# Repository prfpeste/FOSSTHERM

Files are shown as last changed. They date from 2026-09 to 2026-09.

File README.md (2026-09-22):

# FOSSTHERM

Freie und quelloffene Soft- und Hardware für thermische Tischversuche

> **English summary:** FOSSTHERM (Free and Open Source Thermal Experiments) is a collection of Arduino-based benchtop experiments for teaching heat transfer and thermodynamics. Each experiment lives in its own folder and includes hardware files (3D-printable parts, schematics, bill of materials), firmware, evaluation software and documentation. The documentation is written in German; source code and file names are in English.

## Projektziel

Das System wurde bewusst nicht als vollständig industrialisiertes Messsystem ausgelegt, sondern als leicht nachbaubare, offene und kostengünstige Plattform für den Einsatz in Lehre und Labor. Im Vordergrund stehen geringe Materialkosten, die Verwendung gut verfügbarer Standardbauteile, eine leicht nachvollziehbare Schaltungstopologie sowie die Möglichkeit, dass Studierende Module selbst aufbauen, anpassen und im Fehlerfall mit geringem Aufwand austauschen können.

Zusätzliche Maßnahmen zur Erhöhung der Robustheit, der EMV-Festigkeit oder für einen umfassenden Fehlerschutz wurden daher nur insoweit berücksichtigt, wie sie für den vorgesehenen Einsatz in beaufsichtigten Laborumgebungen erforderlich sind. Für Anwendungen in rauen Industrieumgebungen oder mit erhöhten Anforderungen an Zuverlässigkeit und Störfestigkeit sind weitergehende Schutz- und Schnittstellenbeschaltungen notwendig.

Die Versuche entstehen im Rahmen studentischer Projektarbeiten und richten sich an Hochschulen, Schulen und alle, die thermische Grundlagen anschaulich und messtechnisch nachvollziehbar vermitteln möchten.

## Versuche

| Versuch | Inhalt | Status |
| :--- | :--- | :--- |
| [Wärmekapazität](Waermekapazitaet/) | Bestimmung der spezifischen Wärmekapazität von Aluminium, Kupfer und Stahl mittels Wasserkalorimetrie | verfügbar |
| Wärmeleitfähigkeit | | in Arbeit |
| Tripelpunkt | | in Arbeit |

Weitere Versuche werden ergänzt, sobald sie fertiggestellt sind.

## Aufbau des Repositorys

Jeder Versuch liegt in einem eigenen Unterordner mit einheitlicher Gliederung:

```
FOSSTHERM/
├── README.md                  Diese Datei
├── LICENSE-*                  Lizenztexte für Hardware, Software und Dokumentation
└── <Versuch>/
    ├── README.md              Überblick und Schnellstart zum Versuch
    ├── 01_Hardware/           Stückliste, 3D-Druckteile, Zeichnungen, Schaltplan
    ├── 02_Software/           Firmware, Auswertesoftware, Simulation
    └── 03_Documentation/      Handbuch mit Theorie, Bedienung und Sicherheitshinweisen
```

Die README im jeweiligen Versuchsordner beschreibt, welche Dateien im Einzelnen enthalten sind und wie der Versuch in Betrieb genommen wird.

## Mitwirkende

#### Projektleitung und Betreuung

- Prof. Dr. Peter Stein (HTWG Konstanz - Maschinenbau)

#### Entwicklung der Versuche

- Marcel Yigitkurt (Waermekapazitaet - HTWG Konstanz - Maschinenbau)
- Moritz Schubach (Waermekapazitaet - HTWG Konstanz - Maschinenbau)

## Verwandte Projekte

- [FOSSDAQ](https://github.com/prfpeste/FOSSDAQ) – freie und quelloffene modulare Messdatenerfassung für Lehre und Labor

## Lizenz

FOSSTHERM verwendet für verschiedene Teile des Projekts unterschiedliche Lizenzen:

- **Hardware und Konstruktionsdaten** in den Ordnern `01_Hardware/` der einzelnen Versuche unterliegen der Lizenz **CERN-OHL-W-2.0**.
  Siehe [`LICENSE-HARDWARE - CERN-OHL-W-2.0`](LICENSE-HARDWARE%20-%20CERN-OHL-W-2.0).

- **Firmware und Software** in den Ordnern `02_Software/` unterliegen der Lizenz **GPL-3.0-or-later**.
  Siehe [`LICENSE-SOFTWARE - GPL-3.0`](LICENSE-SOFTWARE%20-%20GPL-3.0).

- **Dokumentation** in den Ordnern `03_Documentation/` sowie die README-Dateien unterliegen der Lizenz **CC-BY-SA-4.0**.
  Siehe [`LICENSE-DOCS - CC-BY-SA-4.0`](LICENSE-DOCS%20-%20CC-BY-SA-4.0).

Sofern nicht ausdrücklich anders angegeben, gelten für neue Dateien die Lizenzen ihres übergeordneten Verzeichnisses.

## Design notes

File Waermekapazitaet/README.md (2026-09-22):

# Versuch: Wärmekapazität

Teil von [FOSSTHERM](../README.md) – freie und quelloffene thermische Tischversuche

> **English summary:** Arduino-based benchtop experiment for determining the specific heat capacity of metal samples (aluminium, copper, steel) by water calorimetry. This folder contains 3D-printable parts, a KiCad schematic, Arduino firmware, a Python/Dash dashboard and an OpenModelica model. The documentation is written in German; source code and file names are in English.

## Überblick

In diesem Versuch wird die **spezifische Wärmekapazität metallischer Proben** (Aluminium, Kupfer und Stahl) mittels **Wasserkalorimetrie** bestimmt. Die Probe wird mit Raumtemperatur in heißes Wasser getaucht; aus der Abkühlung des Wassers und der Erwärmung der Probe berechnet das Dashboard automatisch die Wärmekapazität.

Der Aufbau besteht aus:

- einem **Arduino Nano**,
- einem **DS18B20-Temperatursensor** für die Wassertemperatur,
- einem **MAX6675-Messverstärker mit Typ-K-Thermoelement** für die Probentemperatur,
- einem **Python-Dash-Dashboard** zur Live-Messwerterfassung und Berechnung der Wärmekapazität mit Wärmeverlustkorrektur,
- einem **digitalen Zwilling in OpenModelica** zur Simulation und Validierung sowie
- einer **vollständig 3D-druckbaren Mechanik**.

## Aufbau des Ordners

- `README.md`
  Diese Datei: Überblick, Ordneraufbau und Schnellstart.

- `01_Hardware/`
  - `BOM.ods`: Stückliste mit Bezugsquellen und 3D-Druckteilen.
  - `CAD_construction/STL/`: STL-Dateien aller 3D-druckbaren Teile (Grundplatte, Becherhalter, Deckel, Gehäuse, Kabelschellen, Tauchsiederhalterung, Probenhalter usw.).
  - `CAD_construction/test_cube.pdf`: Zeichnung des Probenwürfels.
  - `electrical_schematic/`: KiCad-Schaltplan (`PJ1_Tischversuch_Schaltplan.kicad_sch`) und als PDF exportierter Schaltplan.

- `02_Software/`
  - `Arduino/`: Firmware (`heat_capacity_sketch.ino`) und Liste der benötigten Bibliotheken (`libraries.txt`).
  - `Python/`: Dash-Anwendung (`HeatCapacity_python_code.py`) zur Live-Visualisierung, CSV-Export und Berechnung der Wärmekapazität, Hilfsskript zur Kalibrierung des Wärmeverlusts (`determine_heat_loss_coefficient.py`), Startskript für Linux/macOS (`run_HeatCapacity.sh`) sowie Beispielmessdaten in `data/`.
  - `Open_Modelica_simulation/`: Digitaler Zwilling des Kalorimetrieversuchs (`HeatCapacity_Experiment.mo`) zur Simulation und Validierung.

- `03_Documentation/`
  - `MANUAL.md`: Technisches Handbuch mit Theorie, Kalibrierung, Pinbelegung, Bedienungsanleitung, Sicherheitshinweisen und Fehlersuche.

## Schnellstart

### 1. Firmware

1. `02_Software/Arduino/heat_capacity_sketch.ino` in der Arduino-IDE öffnen.
2. Board **Arduino Nano** auswählen.
3. Über den Bibliotheksverwalter die benötigten Bibliotheken installieren: LiquidCrystal I2C, OneWire, DallasTemperature und MAX6675 (siehe `libraries.txt`).
4. Den richtigen Port wählen und den Sketch hochladen.

### 2. Python-Dashboard

```bash
git clone https://github.com/prfpeste/FOSSTHERM.git
cd FOSSTHERM/Waermekapazitaet/02_Software/Python
python -m venv .venv
source .venv/bin/activate      # Windows: .venv\Scripts\activate
pip install -r requirements.txt
```

Vor dem ersten Start in `HeatCapacity_python_code.py` die Konstante `SERIAL_PORT` an den seriellen Port des Arduino anpassen (voreingestellt ist `COM5`; unter Linux z. B. `/dev/ttyUSB0`, unter macOS z. B. `/dev/cu.usbserial-…`). Anschließend:

```bash
python HeatCapacity_python_code.py
```

Unter Linux/macOS kann alternativ `./run_HeatCapacity.sh` verwendet werden; das Skript legt die virtuelle Umgebung bei Bedarf selbst an.

Danach im Browser http://127.0.0.1:8050 öffnen, Wassermasse, Raumtemperatur und Probenmaterial eingeben und den Versuch starten. Den genauen Messablauf beschreibt das [Handbuch](03_Documentation/MANUAL.md).

### 3. Digitaler Zwilling (optional)

`02_Software/Open_Modelica_simulation/HeatCapacity_Experiment.mo` in OpenModelica (OMEdit) öffnen, um den Kalorimetrievorgang zu simulieren und mit einem aus dem Dashboard exportierten CSV-Datensatz zu vergleichen. Hinweise dazu stehen in der [README des Simulationsordners](02_Software/Open_Modelica_simulation/README.md).

## Voraussetzungen

- Python 3.10 oder neuer (siehe `02_Software/Python/requirements.txt`)
- Arduino-IDE 2.x mit Boardpaket für den Arduino Nano
- OpenModelica 1.22 oder neuer (nur für den digitalen Zwilling)

## Entwicklung des Versuchs

- Marcel Yigitkurt
- Moritz Schubach

## Lizenz

Für die Bestandteile dieses Versuchs gelten die Lizenzen des FOSSTHERM-Repositorys; die Lizenztexte liegen im Hauptverzeichnis:

- **Hardware** (`01_Hardware/`: Schaltplan, 3D-Modelle, Zeichnungen, Stückliste) steht unter **CERN-OHL-W-2.0**.
  Siehe [`LICENSE-HARDWARE - CERN-OHL-W-2.0`](../LICENSE-HARDWARE%20-%20CERN-OHL-W-2.0).

- **Firmware und Software** (`02_Software/`: Arduino, Python, OpenModelica) stehen unter **GPL-3.0-or-later**.
  Siehe [`LICENSE-SOFTWARE - GPL-3.0`](../LICENSE-SOFTWARE%20-%20GPL-3.0).

- **Dokumentation** (`03_Documentation/` und die README-Dateien) steht unter **CC-BY-SA-4.0**.
  Siehe [`LICENSE-DOCS - CC-BY-SA-4.0`](../LICENSE-DOCS%20-%20CC-BY-SA-4.0).

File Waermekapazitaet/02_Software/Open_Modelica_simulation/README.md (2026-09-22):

# OpenModelica: Digitaler Zwilling

Dieser Ordner enthält das physikalische Simulationsmodell des Wärmekapazitäts-Versuchs, erstellt mit OpenModelica. Es dient dazu, den theoretischen Temperaturverlauf zu simulieren und mit den realen, über Python erfassten Sensordaten zu vergleichen.

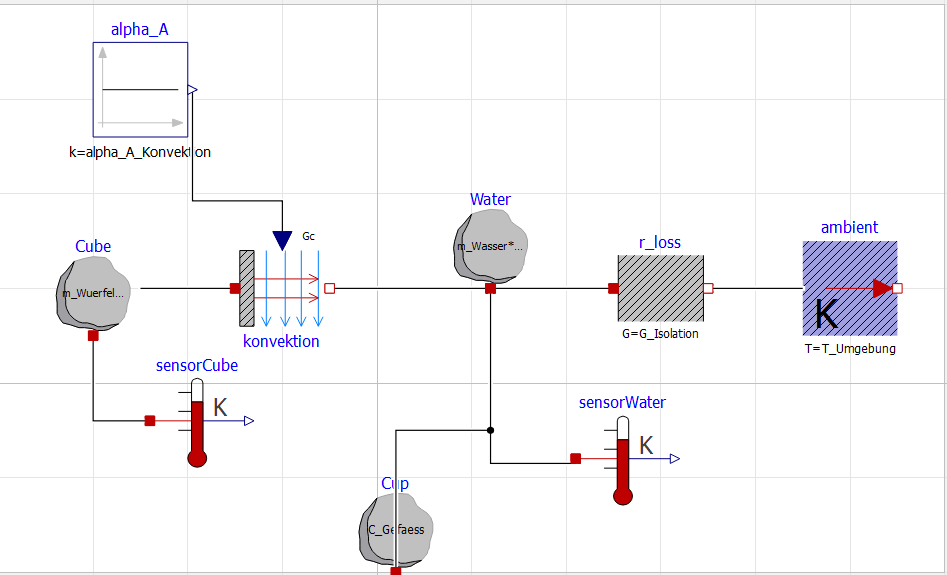
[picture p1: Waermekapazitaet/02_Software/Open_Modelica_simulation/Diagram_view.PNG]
Diagrammansicht des Modells


## Verwendung in OMEdit

1. Die Datei `HeatCapacity_Experiment.mo` in OMEdit öffnen (Modellname: `HeatCapacity_TableTopExperiment_MaterialSelection`).
2. In die **Diagrammansicht** (Diagram View) wechseln.
3. Doppelt auf den leeren Hintergrund klicken, um das Parametermenü zu öffnen. Dort das Material auswählen (`materialSelection`):
   * `1` = Aluminium
   * `2` = Kupfer
   * `3` = Stahl
4. Auf **Simulate** klicken.

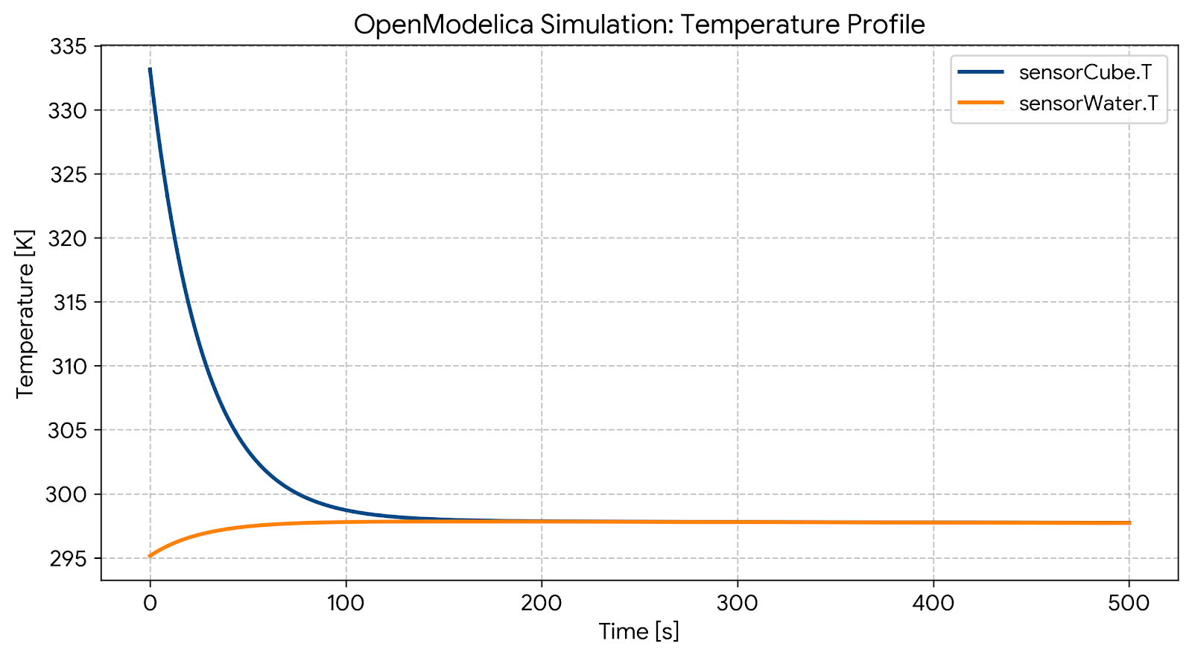
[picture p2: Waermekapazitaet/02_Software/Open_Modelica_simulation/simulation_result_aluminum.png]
Simulationsergebnis für Aluminium


## Starttemperaturen

In der Voreinstellung simuliert das Modell einen heißen Würfel (`T_Wuerfel_Start` = 60 °C) in kaltem Wasser (`T_Wasser_Start` = 22 °C). Im realen Versuch ist es umgekehrt: Der Würfel hat Raumtemperatur und wird in Wasser von ca. 60 °C getaucht. Für einen direkten Vergleich mit Messdaten die beiden Parameter entsprechend tauschen und `T_Umgebung` auf die gemessene Raumtemperatur setzen. Die Auswertungsgleichungen im Modell gelten für beide Richtungen des Wärmeflusses.

## Kalibrierung

Der Parameter `alpha_A_Konvektion` (Wärmeübergang Würfel–Wasser, α·A in W/K) ist im Modell auf `3.5` kalibriert. Mit diesem Wert stellt sich das thermische Gleichgewicht zwischen Aluminiumwürfel und Wasser in der Simulation nach etwa 110 Sekunden ein, wie im realen Laboraufbau.

Der Parameter `G_Isolation` entspricht dem Wärmeverlustkoeffizienten `K_WERT` der Python-Auswertung. Nach einer neuen Kalibrierung (siehe `03_Documentation/MANUAL.md`, Abschnitt 2) sollte er auf denselben Wert gesetzt werden.

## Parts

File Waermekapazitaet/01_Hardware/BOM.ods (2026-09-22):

Bauteil | Genaue Bezeichnung | EAN | Preis pro Stück(ca.) | Stückzahl | Link
Arduino Nano Clon | TRU COMPONENTS MF-6402378 Entwicklungsboard ATmega328 NANO Development Board | 4053199973927 | 5,00 € | 1 | TRU COMPONENTS MF-6402378 Entwicklungsboard ATmega328 NANO Development Board kaufen
Thermoelement_Probestück | Kabel-Thermoelement Typ K mit PVC-Leitung | 803550 1211 | 9,38 € | 3 | Kabel-Thermoelement Typ K mit PVC-Leitung | Testo Sensor GmbH (https://www.testo-sensor.shop/de/kabel-thermoelement-typ-k-mit-pvc-leitung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)
Arduino - Thermoelementmodul, K-Typ, MAX6675 | Arduino - Thermoelementmodul, K-Typ, MAX6675 | 791352940617 | 6,50 € | 1 | FREI Arduino - Thermoelementmodul, K-Typ, MAX6675 | Sensoren & Module günstig kaufen | reichelt elektronik (https://www.reichelt.de/de/de/shop/produkt/arduino_-_thermoelementmodul_k-typ_max6675-282532?PROVID=2378)
Miniaturdose | B + B Thermo-Technik 0220 0005 Miniaturdose Typ K, gelb | -50...+120°C Gelb | 2050000000966 | 4,03 € | 1 | B + B Thermo-Technik 0220 0005 Miniaturdose Typ K, gelb | -50...+120°C Gelb Inhalt: 1 St. kaufen (https://www.conrad.de/de/p/b-b-thermo-technik-0220-0005-miniaturdose-typ-k-gelb-50-120-c-gelb-inhalt-1-st-121365.html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)
Temp-Sensor-Wasser | TRU COMPONENTS TC-9445340 Temperatursensor 1 St. Passend für (Entwicklungskits): Arduino | 4064161170688 | 5,00 € | 2 | TRU COMPONENTS TC-9445340 Temperatursensor 1 St. Passend für (Entwicklungskits): Arduino kaufen
Anzeige (LCD) | Joy-it SBC-LCD16x2 Display-Modul 6.6 cm (2.6 Zoll) 16 x 2 Pixel Passend für (Entwicklungskits): Raspberry Pi®, Arduino, | 4250236813219 | 5,00 € | 1 | https://www.conrad.de/de/search.html?search=Joy-it%20SBC-LCD16x2
Tauchsieder | ECE - EHLERS - ECE-Ehlers RTE 304, AC, 300 W, 230 - 250 V, 50 - 60 Hz, Rot, Kupfer | 4004369003043 | 13,00 € | 1 | https://www.conrad.de/de/p/ece-ehlers-ece-ehlers-rte-304-ac-300-w-230-250-v-50-60-hz-rot-kupfer-827409.html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
Lochrasterplatine | Rademacher WR-Typ 811-2 Platine Hartpapier (L x B) 100 mm x 75 mm 35 µm Rastermaß 2.54 mm Inhalt 1 St. | 4031909007858 | 2,30 € | 1 | Rademacher WR-Typ 811-2 Platine Hartpapier (L x B) 100 mm x 75 mm 35 µm Rastermaß 2.54 mm Inhalt 1 St. kaufen
Micro_USB_Kabel | Digitus USB-Kabel USB 2.0 USB-A Stecker, USB-Micro-B Stecker 1.80 m Schwarz AK-300127-018-S | 4016032314646 | 0,80 € | 1 | Digitus USB-Kabel USB 2.0 USB-A Stecker, USB-Micro-B Stecker 1.80 m Schwarz AK-300127-018-S kaufen
Widerstand 4,7kOhm | Yageo MFR-25FBF52-4K7 Metallschicht-Widerstand 4.7 kΩ 0207 1 % 1 St | MFR-25FBF52-4K7 | 0.02€ | 1 | Yageo MFR-25FBF52-4K7 Metallschicht-Widerstand 4.7 kΩ 0207 1 % 1 St. kaufen
Schaltdraht (massiv) | LAPP 0068001 Hochtemperaturader ÖLFLEX® HEAT 180 SiD 1 x 0.50 mm² Schwarz Meterware | 2050001427120 | 2,25 € | 1 | LAPP 0068001 Hochtemperaturader ÖLFLEX® HEAT 180 SiD 1 x 0.50 mm² Schwarz Meterware kaufen
4-Pin Jumperkabel | Entwicklerboards - Kabel, 4-Pin, Dupon, 20 cm | 791352939147 | 0,42 € | 1 | FREI Entwicklerboards - Kabel, 4-Pin, Dupon, 20 cm | Kabel & Adapter günstig kaufen | reichelt elektronik (https://www.reichelt.de/de/de/shop/produkt/entwicklerboards_-_kabel_4-pin_dupon_20_cm-282689)
Schrumpfschlauch | Sinuslive 373642 Schrumpfschlauchsortiment Schrumpfrate:2:1 1 Set | 4016631005983 | 3,00 € | 1 | Sinuslive 373642 Schrumpfschlauchsortiment Schrumpfrate:2:1 1 Set kaufen
Becherglas Doppelwandiges Glas ( Durchsichtig als auch Isolierend) | Wilmax Doppelwandiges Thermoglas 400 ml Transparent WL-888785/A | 5054428887854 | 10,00 € | 1 | https://www.kaufland.de/product/521053989/
Linsenschraube M 3x30mm DIN7985 |  |  |  | 2
Linsenschraube M 3x10mm DIN7985 |  |  |  | 16
Linsenschraube M 3x15mm DIN7985 |  |  |  | 6
Sechskantmutter M 3 DIN 934 |  |  |  | 20
slotted_base_plate | 20x20-m3-nut_-flat | – | – | 1 | 3D-Druckteil
20x20-m3-nut_-flat | 20x20-m3-nut_-flat | – | – | 14 | 3D-Druckteil
beaker_holder | beaker_holder | – | – | 1 | 3D-Druckteil
beaker_lid | beaker_lid | – | – | 1 | 3D-Druckteil
cable_clamp_1 | cable_clamp_1 | – | – | 3 | 3D-Druckteil
cable_clamp_2 | cable_clamp_2 | – | – | 3 | 3D-Druckteil
cable_feedtrough_cover | cable_feedtrough_cover | – | – | 1 | 3D-Druckteil
electronics_enclosure | electronics_enclosure | – | – | 1 | 3D-Druckteil
electronics_enclosure_cover | electronics_enclosure_cover | – | – | 1 | 3D-Druckteil
immersion_heater_cage | immersion_heater_cage | – | – | 1 | 3D-Druckteil
immersion_heater_mount | immersion_heater_mount | – | – | 1 | 3D-Druckteil
lcd_box_16x2_top | lcd_box_16x2_top | – | – | 1 | 3D-Druckteil
lcd_box_16x2 | lcd_box_16x2 | – | – | 1 | 3D-Druckteil
test_cube_holder | test_cube_holder | – | – | 3 | 3D-Druckteil

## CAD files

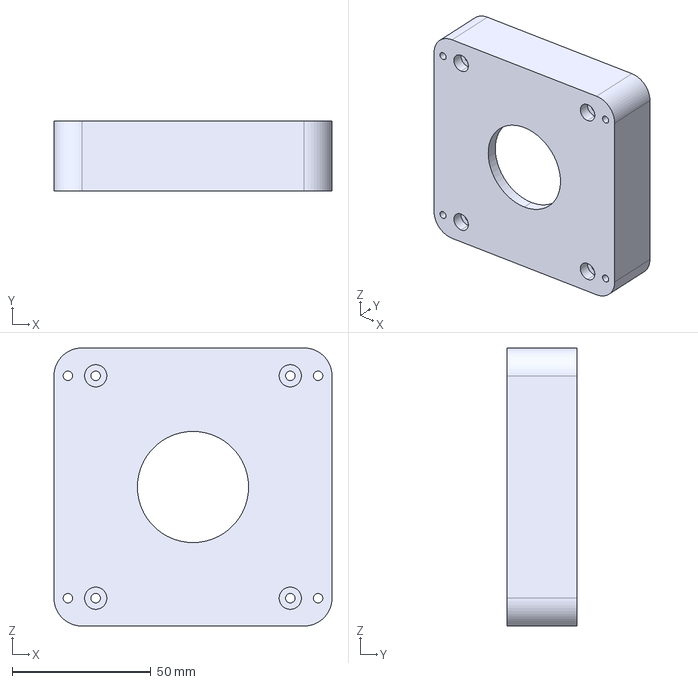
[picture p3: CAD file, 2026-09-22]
Waermekapazitaet/01_Hardware/CAD_construction/STEP/beaker_holder.stp
100.0 x 25.0 x 100.0 mm

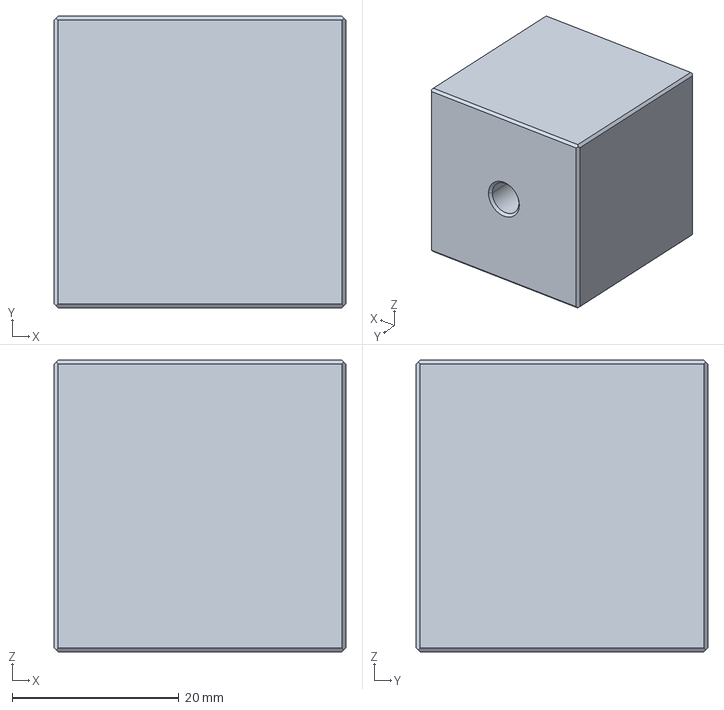
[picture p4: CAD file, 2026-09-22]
Waermekapazitaet/01_Hardware/CAD_construction/STEP/test_cube.stp
35.0 x 35.0 x 35.0 mm

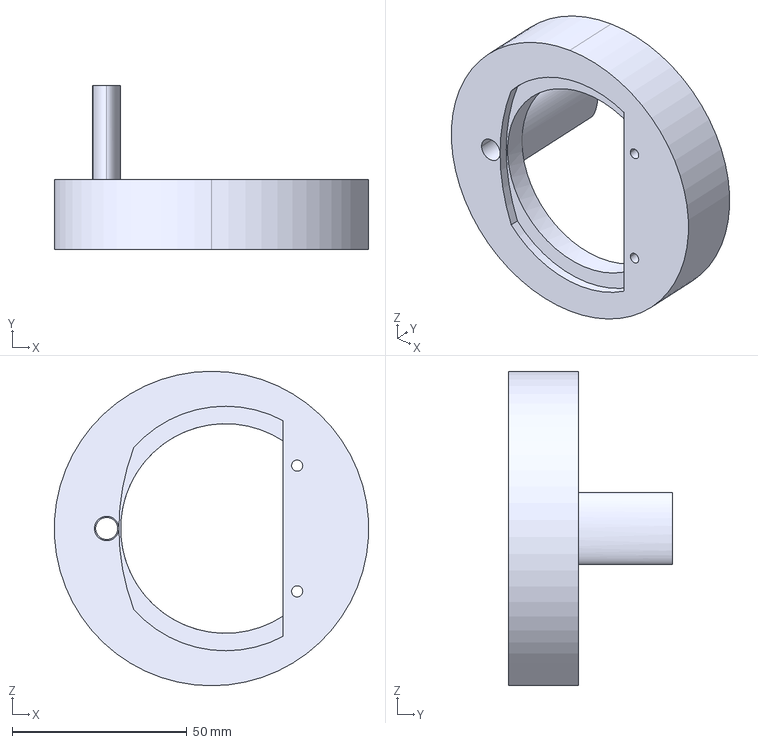
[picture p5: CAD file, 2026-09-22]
Waermekapazitaet/01_Hardware/CAD_construction/STEP/beaker_lid.stp
89.9 x 47.0 x 90.0 mm

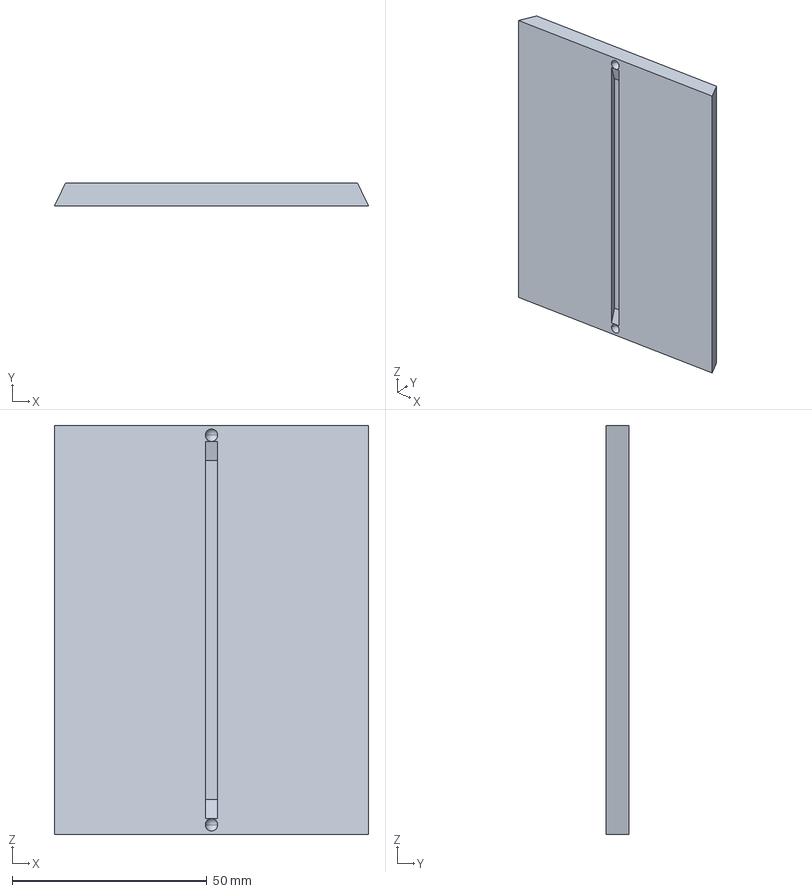
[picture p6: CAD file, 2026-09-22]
Waermekapazitaet/01_Hardware/CAD_construction/STEP/electronics_enclosure_cover.stp
80.8 x 6.00 x 105.1 mm

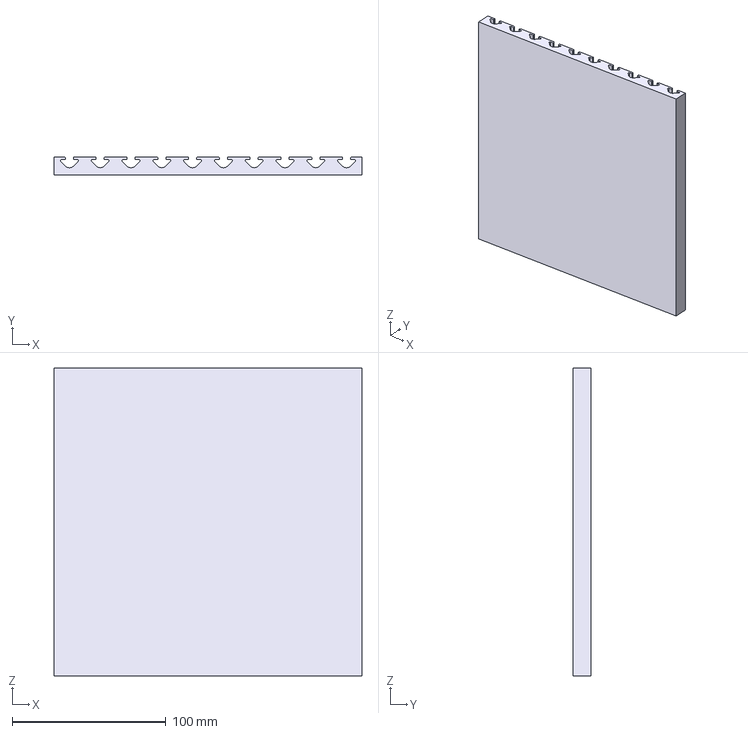
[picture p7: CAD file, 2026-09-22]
Waermekapazitaet/01_Hardware/CAD_construction/STEP/slotted_base_plate.stp
200.0 x 12.0 x 200.0 mm

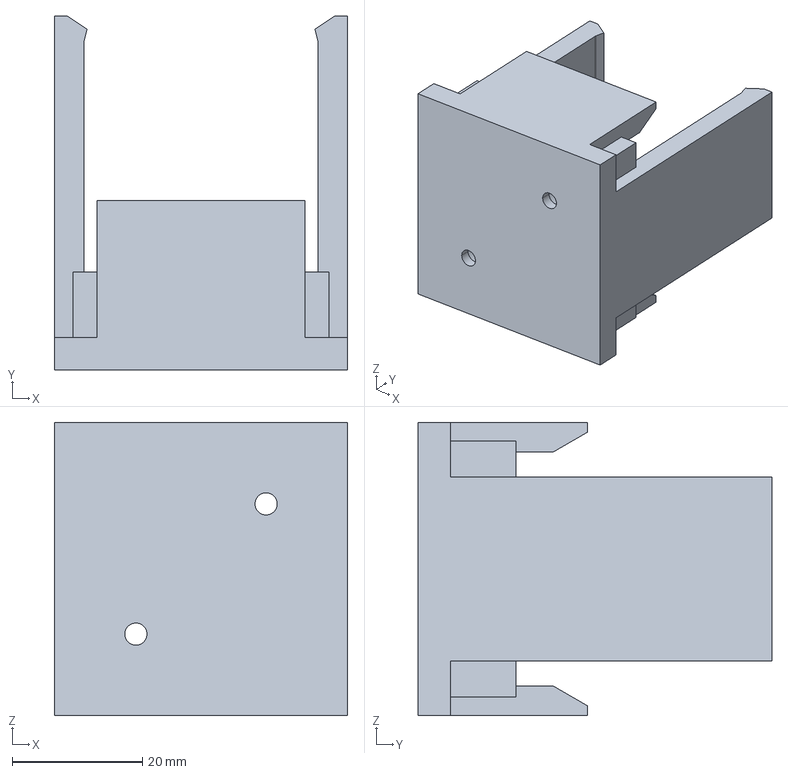
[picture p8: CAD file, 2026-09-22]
Waermekapazitaet/01_Hardware/CAD_construction/STEP/test_cube_holder.stp
45.0 x 54.3 x 45.0 mm

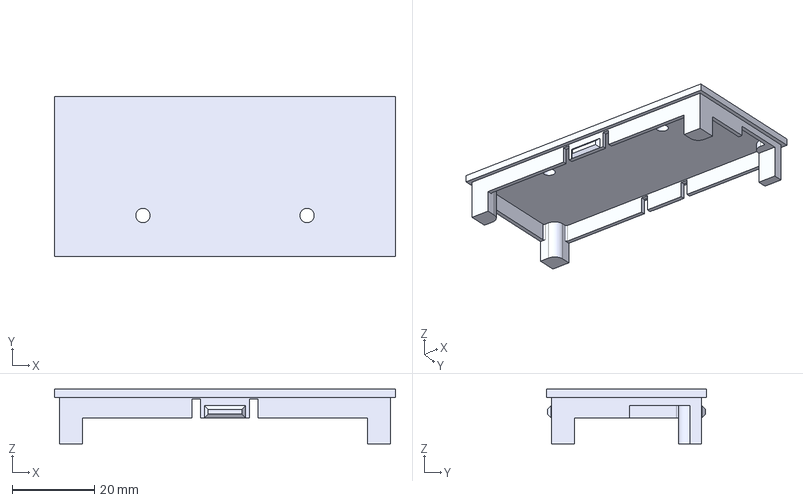
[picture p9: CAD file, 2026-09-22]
Waermekapazitaet/01_Hardware/CAD_construction/STEP/lcd_box_16x2.stp
83.1 x 39.0 x 13.3 mm

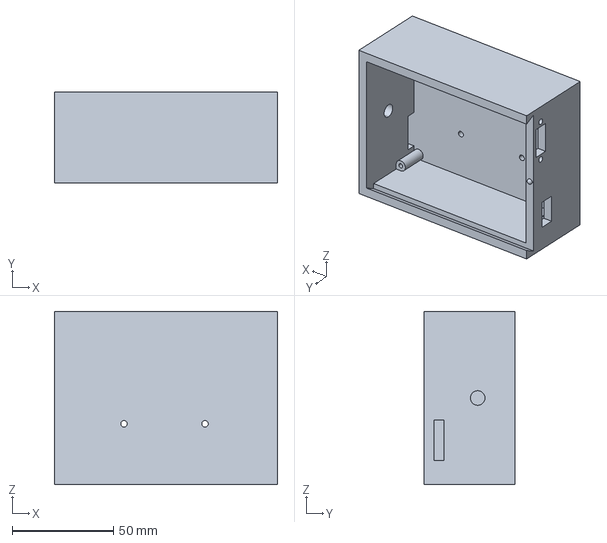
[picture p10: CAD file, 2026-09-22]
Waermekapazitaet/01_Hardware/CAD_construction/STEP/electronics_enclosure.stp
110.1 x 45.0 x 85.5 mm

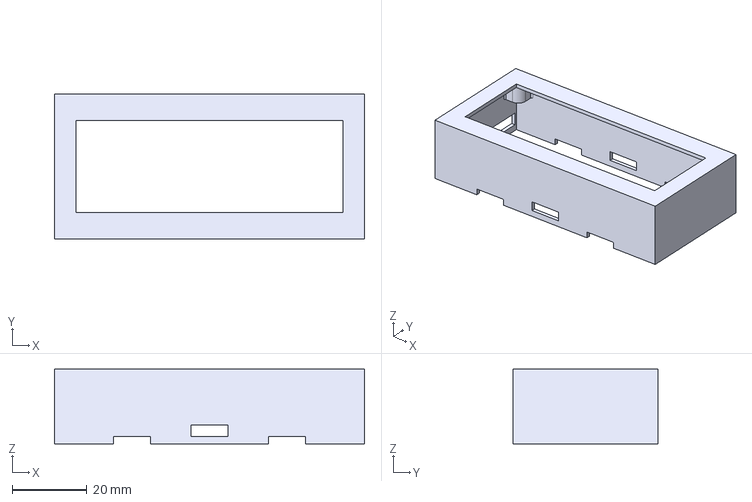
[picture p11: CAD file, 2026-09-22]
Waermekapazitaet/01_Hardware/CAD_construction/STEP/lcd_box_16x2_top.stp
83.1 x 39.0 x 20.0 mm

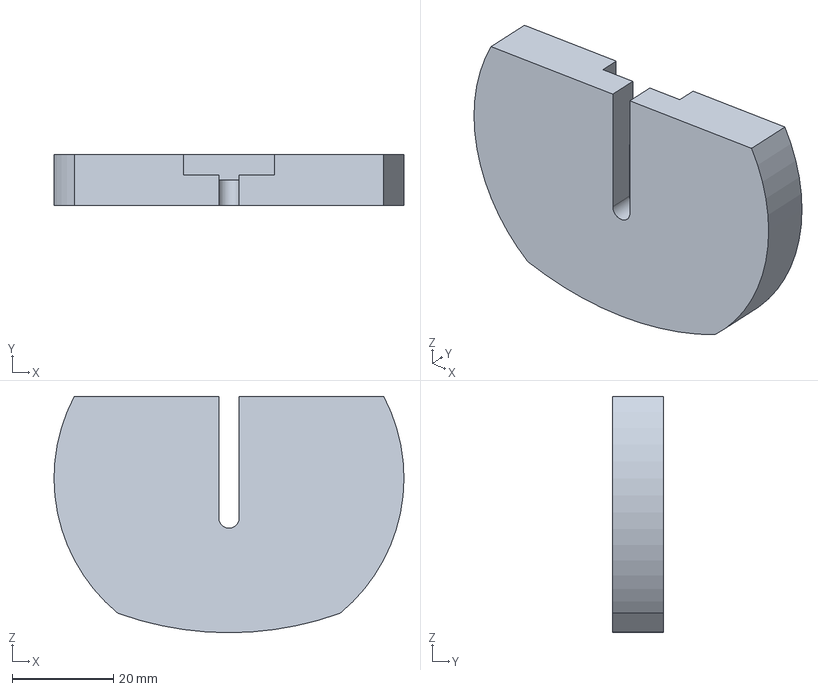
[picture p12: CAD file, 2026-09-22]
Waermekapazitaet/01_Hardware/CAD_construction/STEP/cable_feedtrough_cover.stp
69.0 x 10.0 x 46.6 mm

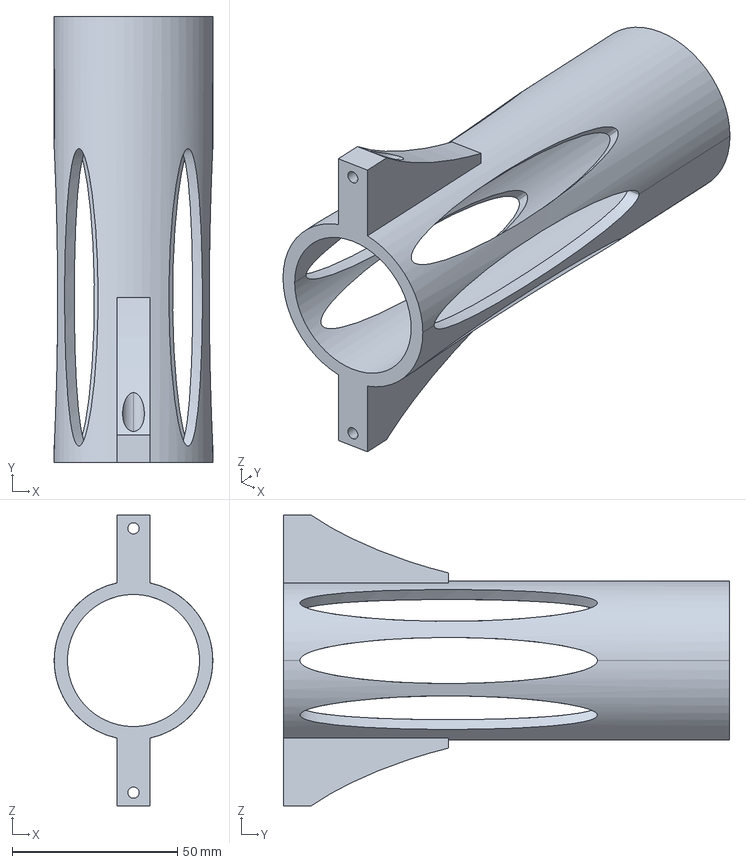
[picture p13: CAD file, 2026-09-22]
Waermekapazitaet/01_Hardware/CAD_construction/STEP/immersion_heater_cage.stp
48.0 x 135.0 x 88.0 mm

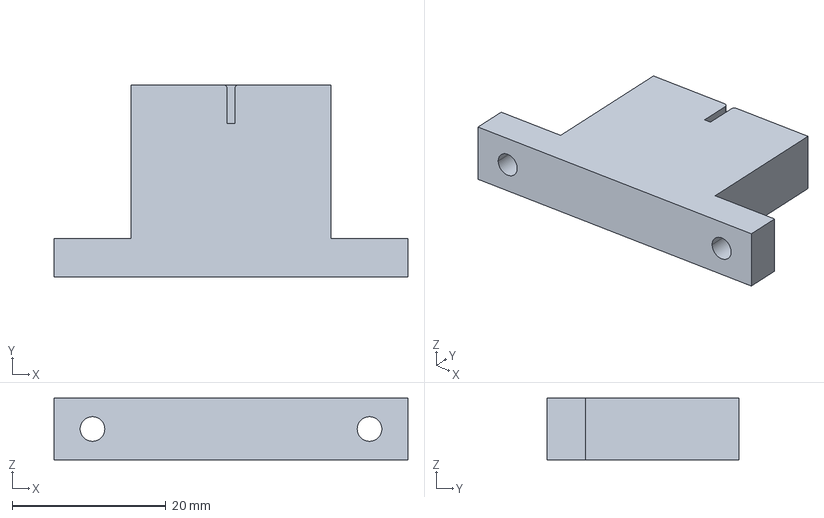
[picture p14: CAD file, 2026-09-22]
Waermekapazitaet/01_Hardware/CAD_construction/STEP/immersion_heater_mount.stp
46.0 x 25.0 x 8.00 mm

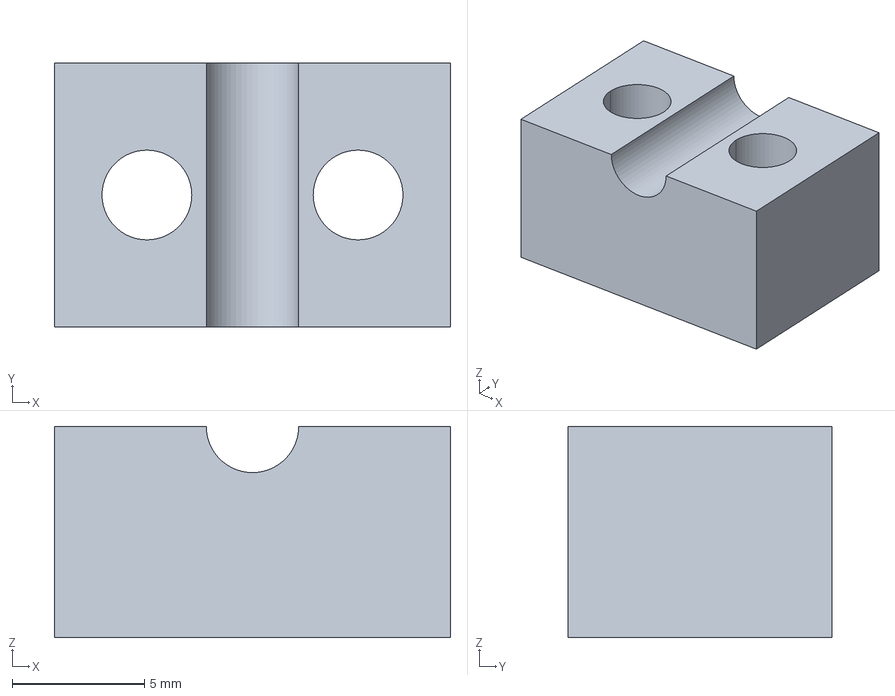
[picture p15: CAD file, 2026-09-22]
Waermekapazitaet/01_Hardware/CAD_construction/STEP/cable_clamp_2.stp
15.0 x 10.0 x 8.00 mm

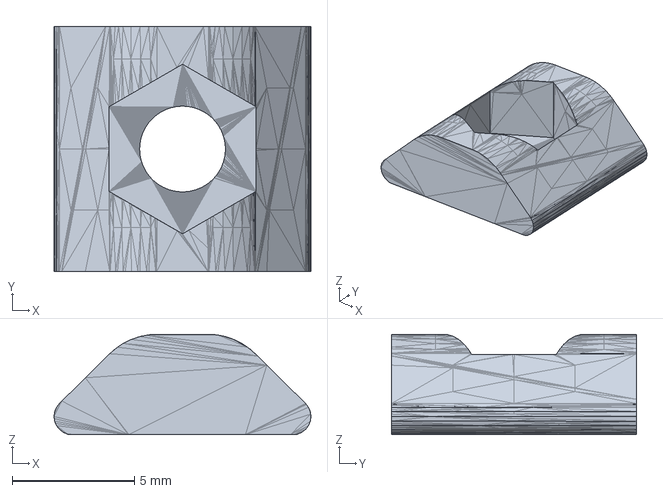
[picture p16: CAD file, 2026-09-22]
Waermekapazitaet/01_Hardware/CAD_construction/STEP/20x20-m3-nut_-flat.stp
10.5 x 10.00 x 4.10 mm

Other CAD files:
Waermekapazitaet/01_Hardware/CAD_construction/STEP/cable_clamp_1.stp
Waermekapazitaet/01_Hardware/CAD_construction/STL/20x20-m3-nut_-flat.stl
Waermekapazitaet/01_Hardware/CAD_construction/STL/beaker_holder.stl
Waermekapazitaet/01_Hardware/CAD_construction/STL/beaker_lid.stl
Waermekapazitaet/01_Hardware/CAD_construction/STL/cable_clamp_1.stl
Waermekapazitaet/01_Hardware/CAD_construction/STL/cable_clamp_2.stl
Waermekapazitaet/01_Hardware/CAD_construction/STL/cable_feedtrough_cover.stl
Waermekapazitaet/01_Hardware/CAD_construction/STL/electronics_enclosure.stl
Waermekapazitaet/01_Hardware/CAD_construction/STL/electronics_enclosure_cover.stl
Waermekapazitaet/01_Hardware/CAD_construction/STL/immersion_heater_cage.stl
Waermekapazitaet/01_Hardware/CAD_construction/STL/immersion_heater_mount.stl
Waermekapazitaet/01_Hardware/CAD_construction/STL/lcd_box_16x2.stl
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

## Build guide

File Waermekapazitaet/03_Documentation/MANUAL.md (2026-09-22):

# FOSSTHERM – Wärmekapazität

## Technisches Handbuch und Bedienungsanleitung

Offene Kalorimetrie-Plattform zur Bestimmung der spezifischen Wärmekapazität fester Stoffe.

**Dokumentversion:** 1.1
**Lizenz:** CC-BY-SA-4.0

---

## 1. Theoretische Grundlagen und Energiebilanz

Ziel des Versuchs ist die Bestimmung der spezifischen Wärmekapazität $c_s$ fester Proben (Aluminium, Kupfer und Stahl) mit Hilfe der Wasserkalorimetrie.

Der Versuch beruht auf der Energieerhaltung zwischen dem heißen Wasser, dem Kalorimetergefäß und der zunächst kalten Metallprobe.

### 1.1 Energieerhaltung

Eine Metallprobe der Masse $m_s$ mit der Anfangstemperatur $T_s$ (etwa Raumtemperatur) wird in heißes Wasser der Masse $m_w$ mit der Anfangstemperatur $T_w$ (etwa 60 °C) getaucht. Wärme fließt vom Wasser in die Probe, bis sich die gemeinsame Mischtemperatur $T_m$ einstellt.

Ohne Wärmeverluste an die Umgebung gilt:

$$Q_\text{ab} = Q_\text{auf}$$

also

$$m_s \, c_s \, (T_m - T_s) = (m_w \, c_w + C_K) \, (T_w - T_m)$$

| Symbol | Bedeutung |
| :--- | :--- |
| $c_s$ | spezifische Wärmekapazität der Probe |
| $c_w$ | spezifische Wärmekapazität von Wasser (4,182 J/(g·K)) |
| $m_s$ | Masse der Probe |
| $m_w$ | Masse des Wassers |
| $C_K$ | effektive Wärmekapazität des Kalorimeters (in der Software `C_GEFAESS` = 50 J/K) |
| $T_s$, $T_w$ | Anfangstemperatur von Probe und Wasser |
| $T_m$ | Mischtemperatur |

Die Wärmekapazität des Kalorimeters umfasst die Beiträge von:

* doppelwandigem Glasgefäß,
* Temperatursensoren,
* mechanischen Bauteilen,
* weiteren wärmespeichernden Teilen.

Der Wert `C_GEFAESS` = 50 J/K ist ein Schätzwert. Er lässt sich bei Bedarf über einen Mischungsversuch mit kaltem und warmem Wasser experimentell bestimmen.

**Umsetzung in der Software:** Als Anfangstemperaturen verwendet das Dashboard den Mittelwert der ersten 10 Messwerte (ca. 5 s) nach dem Start, als Mischtemperatur den Mittelwert der Endtemperaturen von Wasser und Probe (jeweils die letzten 5 Messwerte). Daraus folgt für den Messablauf, dass die Probe erst einige Sekunden nach dem Start eingetaucht werden darf (siehe Abschnitt 6).

---

### 1.2 Wärmeverlustkorrektur

In der Realität tauscht das System Wärme mit der Umgebung aus, und zwar über:

* die Glaswände,
* die offene Wasseroberfläche,
* mechanische Verbindungen.

Deshalb ist eine Wärmeverlustkorrektur erforderlich. Der Verlustwärmestrom wird nach dem Newtonschen Abkühlungsgesetz proportional zur Temperaturdifferenz zwischen Wasser und Umgebung angesetzt:

$$\dot Q_V = K \, (T_w(t) - T_U)$$

mit

* $K$: Wärmeverlustkoeffizient des Aufbaus in W/K (in der Software `K_WERT`),
* $T_U$: Umgebungs- bzw. Raumtemperatur.

Die Software integriert diesen Verlust über die gesamte Messdauer:

$$Q_V = \int K \, (T_w(t) - T_U) \, dt$$

und korrigiert damit die Energiebilanz:

$$m_s \, c_s \, (T_m - T_s) = (m_w \, c_w + C_K) \, (T_w - T_m) - Q_V$$

Der Koeffizient $K$ wird einmalig aus einer Leer-Abkühlkurve ohne Probe bestimmt (siehe Abschnitt 2). Für das reine Abkühlen des Wassers gilt

$$(m_w \, c_w + C_K) \, \frac{dT}{dt} = -K \, (T - T_U)$$

Die Temperaturdifferenz zur Umgebung nimmt also exponentiell ab, mit der Abkühlkonstanten $k = K / (m_w \, c_w + C_K)$.

---

## 2. Kalibrierung des Systems

Eine neue Kalibrierung ist erforderlich, wenn:

* ein anderes Becherglas verwendet wird,
* sich die Wassermenge deutlich ändert,
* der mechanische Aufbau verändert wird,
* der Versuch unter deutlich anderen Umgebungsbedingungen durchgeführt wird.

Der aktuell hinterlegte Wert `K_WERT` = 0,185 W/K wurde aus der mitgelieferten Messung `02_Software/Python/data/measurement_heat_loss.csv` (300 g Wasser, Raumtemperatur 28,25 °C) bestimmt.

---

### 2.1 Aufnahme der Leer-Abkühlkurve

1. Das Becherglas mit ca. 300 g Wasser füllen (am besten wiegen).
2. Den Deckel mit dem Wassertemperatursensor aufsetzen.
3. Den Tauchsieder einsetzen und erst dann einschalten.
4. Das Wasser auf ca. 60 °C erwärmen.
5. Den Tauchsieder ausschalten und vom Netz trennen.
6. Das Wasser gründlich umrühren.
7. Das Thermoelement **ohne Probe** frei an der Luft neben dem Aufbau liegen lassen. Es misst so die Raumtemperatur mit, die später für die Auswertung verwendet wird.
8. Das Dashboard starten (Abschnitt 5), ein beliebiges Material auswählen (ohne Materialauswahl startet die Messung nicht) und auf **Versuch Starten** klicken.
9. Das System mindestens 30 Minuten ungestört abkühlen lassen. Die automatische Abschaltung greift bei dieser Messung nicht, weil Wasser- und Lufttemperatur weit auseinanderliegen. Die Messung daher mit **Stopp** beenden.
10. Mit **CSV Download** die Messdaten exportieren, die Datei in `measurement_heat_loss.csv` umbenennen und im Ordner `02_Software/Python/data/` ablegen.

---

### 2.2 Auswertung der Kalibrierung

Den Wärmeverlustkoeffizienten berechnet das Hilfsskript `determine_heat_loss_coefficient.py`. Es passt die Exponentialfunktion aus Abschnitt 1.2 an die Messdaten an. Im Ordner `02_Software/Python` aufrufen:

```bash
python determine_heat_loss_coefficient.py
```

Ohne weitere Angaben liest das Skript `data/measurement_heat_loss.csv`, nimmt 300 g Wasser an und verwendet den Mittelwert der Thermoelement-Spalte als Raumtemperatur. Abweichende Werte lassen sich übergeben:

```bash
python determine_heat_loss_coefficient.py data/measurement_heat_loss.csv --water-mass 280 --t-room 22.5
```

Den ausgegebenen Wert `K_WERT` in `HeatCapacity_python_code.py` im Abschnitt *KONFIGURATION* eintragen. Für den digitalen Zwilling kann derselbe Wert als Parameter `G_Isolation` im OpenModelica-Modell gesetzt werden.

---

## 3. Hardware

### 3.1 Hauptkomponenten

* **Mikrocontroller und Elektronik**
  * Arduino Nano im Elektronikgehäuse, Stromversorgung und Datenübertragung über USB
  * LCD-Anzeige 16×2 mit I²C-Adapter (Adresse 0x27) zur Live-Anzeige für die Betreuung
* **Temperatursensoren**
  * 1× digitaler Temperatursensor DS18B20 für die Wassertemperatur, mit 4,7-kΩ-Pull-up-Widerstand
  * Typ-K-Thermoelemente für die Probentemperatur, angeschlossen über einen MAX6675-Messverstärker. Laut Stückliste ist je Probenwürfel ein Thermoelement vorgesehen; über die Typ-K-Miniaturkupplung wird jeweils eines an den MAX6675 angeschlossen.
* **Wärmetechnik**
  * Tauchsieder (300 W, 230 V)
  * doppelwandiges Thermoglas (400 ml) als Kalorimetergefäß
* **Proben**
  * Würfel mit 35 mm Kantenlänge aus Aluminium (113 g), Kupfer (377 g) und Stahl (339 g) mit Bohrung für das Thermoelement (Zeichnung: `01_Hardware/CAD_construction/test_cube.pdf`)
* **Mechanik**
  * 3D-gedruckte Teile (Grundplatte, Becherhalter, Deckel, Kabelschellen, Gehäuse, Tauchsiederhalterung, Probenhalter)
* **Normteile**
  * M3-Linsenschrauben und -Muttern gemäß Stückliste

Die Probenmassen sind in der Software fest hinterlegt (`MATERIALS` in `HeatCapacity_python_code.py`). Werden eigene Proben gefertigt, müssen die Massen dort angepasst werden.

### 3.2 Pinbelegung

| Komponente | Signal | Arduino-Pin |
| :--- | :--- | :--- |
| DS18B20 (Wasser) | Daten (1-Wire) | D2 |
| MAX6675 (Probe) | SCK | D13 |
| MAX6675 (Probe) | CS | D10 |
| MAX6675 (Probe) | SO | D12 |
| LCD 16×2 (I²C) | SDA / SCL | A4 / A5 |

Der Arduino sendet alle 500 ms eine JSON-Zeile mit 9600 Baud über die serielle Schnittstelle, z. B. `{"t_water": 58.94, "t_sample": 28.50}`. Ein nicht angeschlossener Sensor wird als `null` übertragen.

### 3.3 Ablage im Repository

* **Stückliste:** `01_Hardware/BOM.ods`
* **3D-Druckteile (STL):** `01_Hardware/CAD_construction/STL/`
* **Zeichnung Probenwürfel:** `01_Hardware/CAD_construction/test_cube.pdf`
* **Schaltplan (KiCad und PDF):** `01_Hardware/electrical_schematic/`
* **Arduino-Firmware:** `02_Software/Arduino/`
* **Python-Auswertesoftware:** `02_Software/Python/` (Beispielmessdaten in `02_Software/Python/data/`)
* **Simulationsmodell:** `02_Software/Open_Modelica_simulation/`

---

## 4. Vorbereitung

1. Das Glasgefäß mit ca. 300 g Wasser füllen und die Masse möglichst genau bestimmen (Waage).
2. Die Raumtemperatur mit einem Referenzthermometer messen.
3. Den Aufbau vor direkter Sonneneinstrahlung und fremden Wärmequellen geschützt aufstellen.
4. Sicherstellen, dass die Probe Raumtemperatur hat.
5. Die Elektronikbox per USB mit dem Rechner verbinden.

---

## 5. Software starten

1. Beim ersten Mal in `HeatCapacity_python_code.py` die Konstante `SERIAL_PORT` an den seriellen Port des Arduino anpassen (Windows z. B. `COM5`, Linux z. B. `/dev/ttyUSB0`, macOS z. B. `/dev/cu.usbserial-…`).
2. Ein Terminal öffnen (z. B. Anaconda Prompt) und in den Python-Ordner wechseln:
   ```bash
   cd FOSSTHERM/Waermekapazitaet/02_Software/Python
   ```
3. Die benötigten Pakete installieren (nur beim ersten Mal):
   ```bash
   pip install -r requirements.txt
   ```
4. Das Dashboard starten:
   ```bash
   python HeatCapacity_python_code.py
   ```
   Unter Linux/macOS alternativ `./run_HeatCapacity.sh`.
5. Die im Terminal angezeigte Adresse (standardmäßig http://127.0.0.1:8050) im Browser öffnen.
6. Im Dashboard Wassermasse (g), Raumtemperatur (°C) und Probenmaterial eintragen bzw. auswählen.

---

## 6. Messablauf

1. Den Tauchsieder in das Wasser einsetzen, erst dann einschalten und das Wasser auf ca. 60 °C erwärmen.
2. Den Tauchsieder ausschalten und den Netzstecker ziehen.
3. Mit dem ausgeschalteten Tauchsieder vorsichtig umrühren, damit sich die Wassertemperatur ausgleicht, dann den Tauchsieder herausnehmen.
4. Das Thermoelementkabel der Probe durch den kleinen Deckeleinsatz führen und den Einsatz in die Hauptöffnung des Deckels setzen.
5. Im Dashboard auf **Versuch Starten** klicken, **ca. 5 Sekunden warten** und erst dann die Probe ins Wasser absenken. In diesen ersten Sekunden erfasst die Software die Anfangstemperaturen von Wasser und Probe.
6. Die Messung endet automatisch, sobald sich Wasser- und Probentemperatur 30 Sekunden lang um höchstens 1 °C unterscheiden. Mit **Stopp** lässt sie sich jederzeit auch manuell beenden.
7. Das Ergebnis prüfen. Angezeigt werden die gemessene spezifische Wärmekapazität in J/(g·K), der Literaturwert, die prozentuale Abweichung, die berücksichtigte Verlustwärme und eine Bewertung (Abweichung unter 15 %: „sehr gut“, unter 35 %: „brauchbar“, darüber: „große Abweichung“).
8. Bei Bedarf die Messdaten mit **CSV Download** exportieren (Datei `Messdaten.csv` mit den Spalten `zeit`, `temp_wasser`, `temp_wuerfel`). Das sollte vor einem neuen Start geschehen, da **Versuch Starten** die bisherigen Daten löscht.

---

## 7. Sicherheitshinweise

Der Versuch arbeitet mit heißem Wasser und einem netzbetriebenen Tauchsieder. Daher gilt:

* Heißes Wasser und erwärmte Proben nicht ohne Schutz berühren.
* Den Tauchsieder nur einschalten, wenn er vollständig im Wasser steht, und vor jeder Handhabung vom Netz trennen.
* Elektrische Komponenten trocken halten.
* Den Versuch nur unter Aufsicht durchführen.

---

## 8. Fehlersuche

### Keine Temperaturwerte (Anzeige „Kein Sensor“ im Dashboard, „---“ auf dem LCD)

* **Prüfen:**
  * USB-Verbindung und Stromversorgung des Arduino
  * Verdrahtung der Sensoren und 4,7-kΩ-Pull-up-Widerstand des DS18B20
  * Steckverbindung des Thermoelements
  * Einstellung `SERIAL_PORT` in `HeatCapacity_python_code.py`
  * ob noch ein anderes Programm (z. B. der serielle Monitor der Arduino-IDE) den Port belegt

### Unplausible Wärmekapazitätswerte

* **Mögliche Ursachen:**
  * nicht ausreichend umgerührt
  * Probe zu früh nach dem Start eingetaucht (Anfangstemperaturen falsch erfasst)
  * Probe hatte keine Raumtemperatur
  * falsch eingetragene Wassermasse oder Raumtemperatur
  * fehlende oder veraltete Wärmeverlustkalibrierung (`K_WERT`, siehe Abschnitt 2)

### Meldungen des Dashboards

* **„kein Gleichgewicht erreicht“:** Wasser und Probe lagen am Ende noch mehr als 1 °C auseinander, z. B. nach einem zu frühen manuellen Stopp. Versuch länger laufen lassen.
* **„Temperaturanstieg der Probe zu gering“:** Die Probe hat sich um weniger als 0,5 K erwärmt. Wassertemperatur und Zeitpunkt des Eintauchens prüfen.
* **„Energiebilanz negativ“:** Die berechnete Verlustwärme übersteigt die vom Wasser abgegebene Wärme. Meist war die Messung zu lang oder `K_WERT` passt nicht zum Aufbau.

### Unruhige Messwerte

* **Prüfen:**
  * lockere mechanische Verbindungen
  * fremde Wärmequellen in der Nähe
  * Kontakt des Thermoelements in der Probenbohrung

---

## 9. Lizenz

Diese Dokumentation ist Teil des Projekts FOSSTHERM und steht unter der Lizenz **CC-BY-SA-4.0** (siehe `LICENSE-DOCS - CC-BY-SA-4.0` im Hauptverzeichnis des Repositorys).

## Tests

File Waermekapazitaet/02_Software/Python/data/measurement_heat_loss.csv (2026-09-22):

zeit | temp_wasser | temp_wuerfel
0.3 | 58.94 | 28.5
0.9 | 58.88 | 28.25
1.5 | 58.94 | 28.5
2.1 | 58.94 | 27.5
2.7 | 58.94 | 28.0
3.3 | 58.94 | 28.25
3.9 | 58.94 | 28.0
4.5 | 58.94 | 27.5
5.1 | 58.94 | 28.25
5.8 | 58.94 | 28.0
6.3 | 58.94 | 28.25
7.0 | 58.94 | 28.0
7.6 | 58.94 | 27.75
8.2 | 58.94 | 28.25
8.8 | 58.94 | 28.25
9.4 | 58.94 | 28.25
10.0 | 58.94 | 28.0
10.6 | 58.94 | 27.75
11.2 | 58.94 | 28.0
11.8 | 58.94 | 28.25
12.4 | 58.94 | 28.5
13.0 | 58.94 | 27.75
13.6 | 58.88 | 28.0
14.2 | 58.94 | 28.0
14.8 | 58.94 | 28.0
15.4 | 58.94 | 28.0
16.0 | 58.94 | 27.75
16.6 | 58.94 | 28.5
17.2 | 58.94 | 27.75
17.8 | 58.88 | 28.0
18.4 | 58.88 | 28.0
19.0 | 58.94 | 27.75
19.6 | 58.88 | 27.75
20.2 | 58.88 | 27.25
20.8 | 58.88 | 28.0
21.4 | 58.88 | 27.75
22.0 | 58.88 | 28.25
22.6 | 58.88 | 27.75
23.2 | 58.88 | 27.75
23.8 | 58.88 | 28.0
24.4 | 58.88 | 28.0
25.0 | 58.88 | 28.0
25.6 | 58.88 | 27.75
26.2 | 58.81 | 27.75
26.8 | 58.88 | 27.75
27.4 | 58.88 | 28.0
28.0 | 58.81 | 28.0
28.6 | 58.81 | 28.5
29.2 | 58.81 | 28.0
29.8 | 58.81 | 27.75
30.4 | 58.81 | 28.0
31.0 | 58.88 | 28.0
31.6 | 58.81 | 28.0
32.2 | 58.81 | 28.0
32.8 | 58.81 | 28.0
33.4 | 58.81 | 27.75
34.0 | 58.81 | 28.0
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

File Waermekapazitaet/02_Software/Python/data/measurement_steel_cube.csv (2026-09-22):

zeit | temp_wasser | temp_wuerfel
0.6 | 61.44 | 28.75
1.2 | 61.38 | 28.5
1.8 | 61.38 | 28.5
2.4 | 61.38 | 29.0
3.0 | 61.38 | 28.25
3.6 | 61.38 | 29.0
4.2 | 61.38 | 28.5
4.8 | 61.38 | 28.25
5.4 | 61.38 | 28.5
6.0 | 61.38 | 28.5
6.6 | 61.38 | 28.5
7.2 | 61.38 | 28.75
7.8 | 61.38 | 28.75
8.4 | 61.38 | 28.75
9.0 | 61.25 | 28.75
9.6 | 61.19 | 28.75
10.2 | 61.13 | 28.75
10.8 | 61.0 | 28.75
11.4 | 60.94 | 28.75
12.0 | 60.94 | 29.0
12.6 | 60.88 | 29.0
13.2 | 60.81 | 29.0
13.8 | 60.75 | 29.0
14.4 | 60.75 | 28.75
15.0 | 60.69 | 29.25
15.6 | 60.69 | 29.25
16.2 | 60.63 | 29.75
16.8 | 60.63 | 29.25
17.5 | 60.56 | 29.5
18.0 | 60.56 | 29.5
18.6 | 60.56 | 30.0
19.3 | 60.5 | 30.75
19.8 | 60.5 | 30.5
20.5 | 60.5 | 30.5
21.1 | 60.5 | 30.75
21.7 | 60.5 | 30.75
22.3 | 60.5 | 31.25
22.9 | 60.5 | 31.5
23.5 | 60.5 | 31.25
24.1 | 60.44 | 31.5
24.7 | 60.44 | 32.0
25.3 | 60.44 | 32.25
25.9 | 60.44 | 33.0
26.5 | 60.44 | 33.0
27.1 | 60.38 | 33.0
27.7 | 60.38 | 34.0
28.3 | 60.38 | 34.0
28.9 | 60.31 | 34.5
29.5 | 60.25 | 34.25
30.1 | 60.25 | 34.75
30.7 | 60.25 | 35.5
31.3 | 60.19 | 35.25
31.9 | 60.19 | 35.25
32.5 | 60.19 | 35.75
33.1 | 60.19 | 36.0
33.7 | 60.13 | 36.5
34.3 | 60.13 | 37.0
34.9 | 60.13 | 37.0
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

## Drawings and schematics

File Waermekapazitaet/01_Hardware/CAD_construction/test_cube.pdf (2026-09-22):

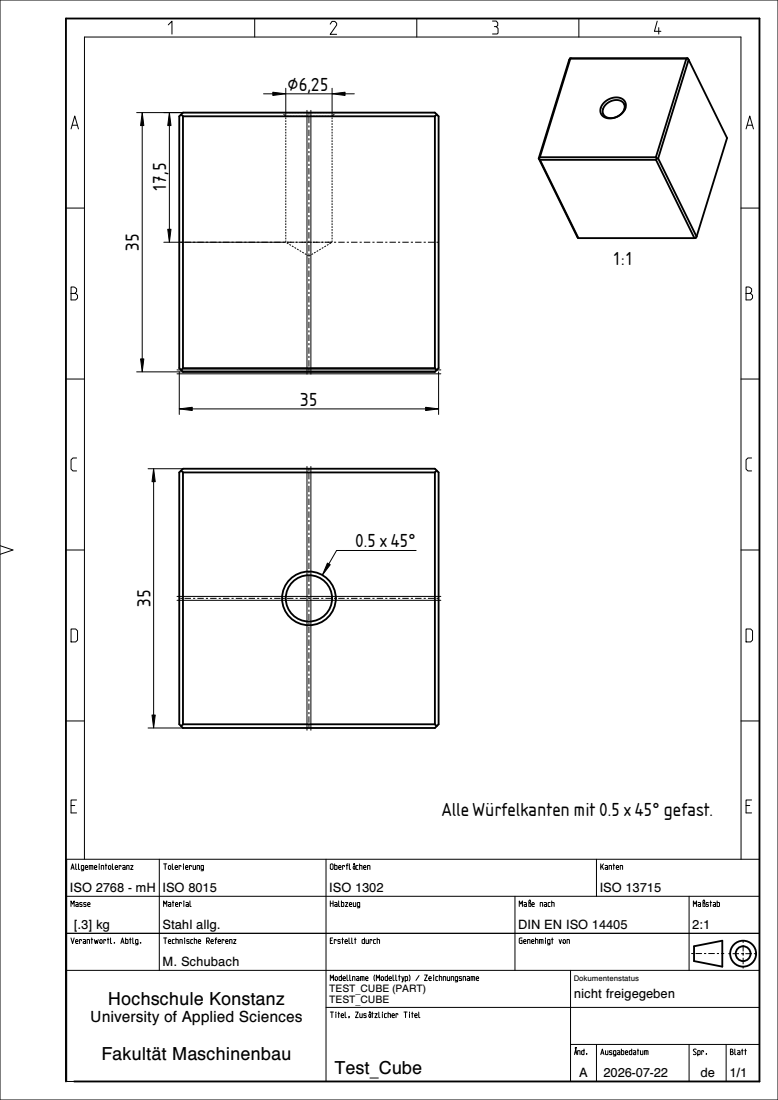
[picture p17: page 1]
Verantwortl.; Abtlg.; Technische Referenz; Erstellt durch; Genehmigt von; Titel, Zusätzlicher; Titel; Masse; Material; Halbzeug; Maße nach; Maßstab; ISO 2768 - mH; ISO 8015; ISO 1302; ISO 13715; Stahl allg.; DIN EN ISO 14405

Alle Würfelkanten mit 0.5 x 45° gefast.

M. Schubach

Hochschule Konstanz University of Applied Sciences Fakultät Maschinenbau | Modellname (Modelltyp) / Zeichnungsname TEST_CUBE (PART) TEST_CUBE | Dokumentenstatus nicht freigegeben

Änd. A | Ausgabedatum 2026-07-22 | Spr. de | Blatt 1/1
Test_Cube

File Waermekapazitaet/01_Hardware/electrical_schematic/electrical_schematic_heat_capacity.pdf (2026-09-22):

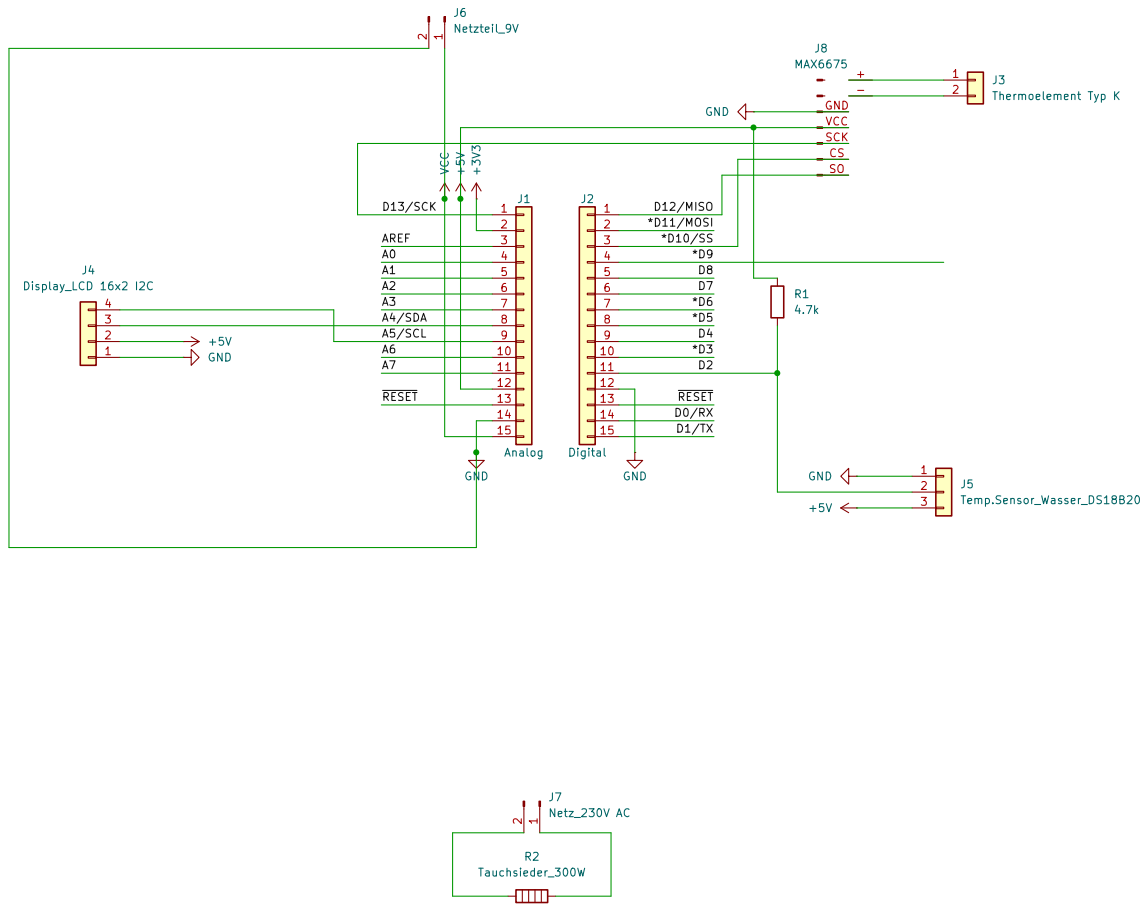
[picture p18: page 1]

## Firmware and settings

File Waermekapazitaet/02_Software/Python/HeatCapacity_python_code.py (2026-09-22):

import sys
import subprocess

# --- AUTO-INSTALLER ---
try:
    import pandas as pd
except ImportError:
    subprocess.check_call([sys.executable, '-m', 'pip', 'install', 'pandas'])
    import pandas as pd

import threading
import time
import json
import dash
from dash import dcc, html, Input, Output, State
import plotly.graph_objs as go
import serial

# =========================================================
# KONFIGURATION
# =========================================================

SERIAL_PORT = 'COM5'
BAUD_RATE = 9600

# Apparatekonstante (Becher + Sensoren)
C_GEFAESS = 50     # J/K

# Kalibrierter Waermeverlustkoeffizient
# Ermittelt aus der Leer-Abkuehlkurve data/measurement_heat_loss.csv (Raumtemperatur 28.25 °C),
# Neuberechnung mit determine_heat_loss_coefficient.py (siehe 03_Documentation/MANUAL.md)
K_WERT = 0.185        # W/K

# Ab welcher Abweichung zwischen Wasser- und Probe-Endtemperatur die
# Gleichgewichtsannahme (Tf = Mittel beider Endwerte) als verletzt gilt.
EQUILIBRIUM_WARN_DELTA = 1.0  # °C

MATERIALS = {
    'Stahl':     {'masse_g': 339},
    'Kupfer':    {'masse_g': 377},
    'Aluminium': {'masse_g': 113}
}

# =========================================================
# DATENSPEICHER
# =========================================================

data_store = {'zeit': [], 'temp_wasser': [], 'temp_wuerfel': []}

# NEU: None statt 0.0, damit "noch kein gueltiger Wert erhalten" von
# "Wert ist 0.0 Grad" unterscheidbar ist.
latest_values = {'t_water': None, 't_sample': None}

# NEU: Zeitpunkt der letzten gueltigen Aktualisierung pro Sensor.
last_update = {'t_water': 0.0, 't_sample': 0.0}

# NEU: Wert, den euer Arduino-Sketch bei nicht angeschlossenem Sensor sendet.
# -127.0 ist der Standard-Fehlerwert der DallasTemperature/DS18B20-Bibliothek.
# Falls euer Sketch stattdessen NaN, -1000 o.ae. sendet: hier anpassen.
SENSOR_ERROR_VALUE = -127.0

# NEU: Nach dieser Zeit ohne gueltigen neuen Wert gilt ein Sensor als
# getrennt, auch wenn kein expliziter Fehlerwert gesendet wird
# (z.B. bei Kabelbruch statt sauberem Abstecken).
SENSOR_TIMEOUT_S = 3.0

experiment_state = {'running': False, 'finished': False}

# Race-Condition-Schutz
data_lock = threading.Lock()

start_time = 0

# =========================================================
# SERIELLE DATEN EINLESEN
# =========================================================

def read_from_arduino():
    try:
        ser = serial.Serial(SERIAL_PORT, BAUD_RATE, timeout=2)

        while True:
            line = ser.readline().decode('utf-8').strip()

            if line:
                try:
                    data = json.loads(line)

                    with data_lock:
                        now = time.time()

                        # NEU: Wasser und Probe unabhaengig voneinander
                        # aktualisieren -- ein fehlender/fehlerhafter Wert
                        # bei einem Sensor blockiert den anderen nicht mehr.
                        tw = data.get('t_water')
                        if tw is not None and tw != SENSOR_ERROR_VALUE:
                            latest_values['t_water'] = tw
                            last_update['t_water'] = now

                        ts = data.get('t_sample')
                        if ts is not None and ts != SENSOR_ERROR_VALUE:
                            latest_values['t_sample'] = ts
                            last_update['t_sample'] = now

                        if experiment_state['running']:
                            elapsed = round(now - start_time, 1)

                            data_store['zeit'].append(elapsed)
                            data_store['temp_wasser'].append(latest_values['t_water'])
                            data_store['temp_wuerfel'].append(latest_values['t_sample'])

                except:
                    pass

    except:
        pass

thread = threading.Thread(target=read_from_arduino, daemon=True)
thread.start()

# =========================================================
# DASH APP
# =========================================================

app = dash.Dash(__name__)

# =========================================================
# LAYOUT
# =========================================================

app.layout = html.Div(
    style={
        'padding': '40px',
        'backgroundColor': '#f4f7f6',
        'fontFamily': 'Segoe UI'
    },
    children=[

        dcc.Download(id='download-csv'),

        html.H1(
            'Wärmekapazitätsversuch',
            style={'textAlign': 'center'}
        ),

        html.Div(
            style={
                'display': 'flex',
                'justifyContent': 'center',
                'gap': '20px',
                'marginBottom': '20px'
            },
            children=[

                html.Div(
                    style={
                        'padding': '15px',
                        'backgroundColor': '#2c3e50',
                        'color': 'white',
                        'borderRadius': '8px',
                        'width': '150px',
                        'textAlign': 'center'
                    },
                    children=[
                        html.H4('Wasser', style={'margin': '0'}),
                        html.Div(
                            id='live-water',
                            style={'fontSize': '28px', 'fontWeight': 'bold'}
                        )
                    ]
                ),

                html.Div(
                    style={
                        'padding': '15px',
                        'backgroundColor': '#c0392b',
                        'color': 'white',
                        'borderRadius': '8px',
                        'width': '150px',
                        'textAlign': 'center'
                    },
                    children=[
                        html.H4('Probe', style={'margin': '0'}),
                        html.Div(
                            id='live-sample',
                            style={'fontSize': '28px', 'fontWeight': 'bold'}
                        )
                    ]
                )
            ]
        ),

        dcc.Graph(id='live-graph', style={'height': '400px'}),

        dcc.Interval(id='graph-update', interval=500),

        html.Div(
            style={
                'padding': '20px',
                'backgroundColor': 'white',
                'borderRadius': '10px',
                'boxShadow': '0 2px 5px rgba(0,0,0,0.1)'
            },
            children=[

                html.H3('Versuchssteuerung'),

                html.Div(
                    style={'display': 'flex', 'gap': '20px', 'marginBottom': '15px', 'alignItems': 'center'},
                    children=[
                        html.Div([
                            html.Label('Wassermasse (g):', style={'fontWeight': 'bold', 'marginRight': '10px'}),
                            dcc.Input(id='input-wasser-masse', type='number', value=300.0, step=1.0, style={'width': '80px'}),
                        ]),
                        html.Div([
                            html.Label('Raumtemperatur (°C):', style={'fontWeight': 'bold', 'marginRight': '10px'}),
                            dcc.Input(id='input-raum-temp', type='number', value=22.0, step=0.1, style={'width': '80px'}),
                        ])
                    ]
                ),

                dcc.Dropdown(
                    id='mat-select',
                    options=[
                        {'label': 'Aluminium (113g)', 'value': 'Aluminium'},
                        {'label': 'Kupfer (377g)', 'value': 'Kupfer'},
                        {'label': 'Stahl (339g)', 'value': 'Stahl'}
                    ],
                    style={'marginBottom': '20px'}
                ),

                html.Div(
                    style={'display': 'flex', 'gap': '10px'},
                    children=[

                        html.Button(
                            'Versuch Starten',
                            id='start-btn',
                            style={
                                'padding': '10px 20px',
                                'fontSize': '16px',
                                'backgroundColor': '#27ae60',
                                'color': 'white',
                                'border': 'none',
                                'borderRadius': '5px',
                                'cursor': 'pointer'
                            }
                        ),

                        html.Button(
                            'Stopp',
                            id='stop-btn',
                            style={
                                'padding': '10px 20px',
                                'fontSize': '16px',
                                'backgroundColor': '#e74c3c',
                                'color': 'white',
                                'border': 'none',
                                'borderRadius': '5px',
                                'cursor': 'pointer'
                            }
                        ),

                        html.Button(
                            'CSV Download',
                            id='download-btn',
                            style={
                                'padding': '10px 20px',
                                'fontSize': '16px',
                                'backgroundColor': '#f39c12',
                                'color': 'white',
                                'border': 'none',
                                'borderRadius': '5px',
                                'cursor': 'pointer'
                            }
                        )
                    ]
                ),

                html.Div(
                    id='status-indicator',
                    style={
                        'marginTop': '20px',
                        'fontSize': '20px',
                        'fontWeight': 'bold'
                    }
                ),

                html.Div(id='calc-output')
            ]
        )
    ]
)

# =========================================================
# HILFSFUNKTIONEN
# =========================================================

def format_temp(key):
    """NEU: zeigt 'Kein Sensor' statt eines eingefrorenen/alten Werts,
    wenn fuer diesen Sensor noch nie ein gueltiger Wert kam oder der
    letzte gueltige Wert laenger als SENSOR_TIMEOUT_S her ist."""
    wert = latest_values[key]
    if wert is None or (time.time() - last_update[key]) > SENSOR_TIMEOUT_S:
        return 'Kein Sensor'
    return f'{wert:.2f} °C'


def mean_last(values, n=5):
    if len(values) < n:
        return sum(values) / len(values)
    return sum(values[-n:]) / n


def _sorted_unique(times, temps):
    """Zeit/Temperatur-Paare nach Zeit sortieren und Duplikate entfernen,
    bevor integriert wird -- ungeordnete oder doppelte Zeitstempel vom
    Arduino wuerden integrate_heat_loss sonst verfaelschen."""
    pairs = sorted(zip(times, temps), key=lambda p: p[0])
    out_t, out_T = [], []
    last_t = None
    for t, T in pairs:
        if last_t is not None and t == last_t:
            continue
        out_t.append(t)
        out_T.append(T)
        last_t = t
    return out_t, out_T


def integrate_heat_loss(times, temps, t_raum):
    '''Integriert den Waermeverlust ueber alle Messpunkte
    (Trapezregel statt linker Rechtecksumme -- etwas genauer bei
    ungleichmaessigen Abtastintervallen).'''

    times, temps = _sorted_unique(times, temps)

    e_loss = 0.0

    for i in range(len(times) - 1):
        dt = times[i + 1] - times[i]
        T_avg = (temps[i] + temps[i + 1]) / 2.0

        # Newtonsche Abkuehlung
        e_loss += K_WERT * (T_avg - t_raum) * dt

    return e_loss


# =========================================================
# CALLBACK
# =========================================================

@app.callback(
    [
        Output('live-water', 'children'),
        Output('live-sample', 'children'),
        Output('live-graph', 'figure'),
        Output('status-indicator', 'children'),
        Output('calc-output', 'children')
    ],
    [
        Input('graph-update', 'n_intervals'),
        Input('start-btn', 'n_clicks'),
        Input('stop-btn', 'n_clicks')
    ],
    [
        State('mat-select', 'value'),
        State('input-wasser-masse', 'value'),
        State('input-raum-temp', 'value')
    ]
)

def update_dashboard(n, start_clicks, stop_clicks, material, wasser_masse, t_raum):

    global start_time

    ctx = dash.callback_context

    # Fallback für leere Eingabefelder
    wasser_masse = float(wasser_masse) if wasser_masse is not None else 300.0
    t_raum = float(t_raum) if t_raum is not None else 22.0

    # =====================================================
    # START / STOP
    # =====================================================

    if ctx.triggered:

        button_id = ctx.triggered[0]['prop_id'].split('.')[0]

        if button_id == 'start-btn' and material:

            experiment_state.update({
                'running': True,
                'finished': False
            })

            with data_lock:
                data_store['zeit'].clear()
                data_store['temp_wasser'].clear()
                data_store['temp_wuerfel'].clear()

            start_time = time.time()

            return (
                format_temp('t_water'),
                format_temp('t_sample'),
                go.Figure(),
                'Status: MESSUNG LÄUFT',
                ''
            )

        elif button_id == 'stop-btn':

            experiment_state['running'] = False
            experiment_state['finished'] = True
        # =====================================================
        # AUTOMATISCHER STOPP
        # =====================================================
        if experiment_state['running'] and len(data_store['zeit']) > 20:
            # NEU: latest_values kann jetzt None sein (Sensor noch nie
            # gueltig empfangen) -- ohne diese Absicherung wuerde die
            # abs()-Differenz weiter unten mit TypeError abstuerzen.
            if (
                latest_values['t_water'] is not None
                and latest_values['t_sample'] is not None
                and abs(latest_values['t_water'] - latest_values['t_sample']) <= 1
            ):
                # Timer initialisieren, falls noch nicht vorhanden
                if 'stability_start' not in experiment_state:
                    experiment_state['stability_start'] = time.time()
                # Stoppen, wenn Wasser und Probe 30 Sekunden lang hoechstens 1 °C auseinanderliegen
                elif time.time() - experiment_state['stability_start'] >= 30:
                    experiment_state['running'] = False
                    experiment_state['finished'] = True
            else:
                # Timer zuruecksetzen, falls Differenz wieder > 1 °C
                experiment_state.pop('stability_start', None)
        # =====================================================
        # ENDE AUTOMATISCHER STOPP
        # =====================================================

    # =====================================================
    # GRAPH
    # =====================================================

    with data_lock:
        zeit = list(data_store['zeit'])
        temp_wasser = list(data_store['temp_wasser'])
        temp_wuerfel = list(data_store['temp_wuerfel'])

    fig = go.Figure()

    fig.add_trace(
        go.Scatter(
            x=zeit,
            y=temp_wasser,
            name='Wasser',
            line=dict(color='#2c3e50')
        )
    )

    fig.add_trace(
        go.Scatter(
            x=zeit,
            y=temp_wuerfel,
            name='Probe',
            line=dict(color='#c0392b')
        )
    )

    fig.update_layout(
        template='plotly_white',
        xaxis_title='Zeit [s]',
        yaxis_title='Temperatur [°C]',
        margin=dict(l=40, r=40, t=20, b=20)
    )

    # =====================================================
    # BERECHNUNG
    # =====================================================

    result_div = html.Div()

    if (
        experiment_state['finished']
        and material
        and len(zeit) > 15
    ):

        try:

            # -------------------------------------------------
            # STARTWERTE
            # -------------------------------------------------

            t_w_start = sum(temp_wasser[:10]) / 10
            t_e_start = sum(temp_wuerfel[:10]) / 10

            # -------------------------------------------------
            # ENDTEMPERATUREN (gemittelt)
            # -------------------------------------------------

            t_w_end = mean_last(temp_wasser, 5)
            t_e_end = mean_last(temp_wuerfel, 5)

            # -------------------------------------------------
            # GLEICHGEWICHTS-PLAUSIBILITAET
            # -------------------------------------------------
            # Tf = Mittel aus beiden Endwerten ist nur zulaessig, wenn
            # Wasser und Probe am Messende bereits (annaehernd) im
            # Gleichgewicht sind. Sonst verfaelscht die Annahme deltaTw
            # und deltaTe direkt.

            equilibrium_gap = abs(t_w_end - t_e_end)

            # Gemeinsame Endtemperatur
            Tf = (t_w_end + t_e_end) / 2

            # -------------------------------------------------
            # DELTA T
            # -------------------------------------------------

            deltaTw = t_w_start - Tf
            deltaTe = Tf - t_e_start

            # -------------------------------------------------
            # WÄRMEVERLUST INTEGRIEREN
            # -------------------------------------------------

            e_loss = integrate_heat_loss(zeit, temp_wasser, t_raum)

            # -------------------------------------------------
            # ENERGIEBILANZ
            # -------------------------------------------------

            Q_wasser = (
                wasser_masse * 4.182 + C_GEFAESS
            ) * deltaTw

            Q_probe = Q_wasser - e_loss

            # -------------------------------------------------
            # PLAUSIBILITÄT
            # -------------------------------------------------

            if equilibrium_gap > EQUILIBRIUM_WARN_DELTA:

                result_div = html.Div(
                    f'Wasser und Probe liegen am Messende noch '
                    f'{equilibrium_gap:.1f} °C auseinander -- kein '
                    f'Gleichgewicht erreicht. Tf-Annahme (Mittelwert) ist '
                    f'hier nicht gueltig, Ergebnis unzuverlaessig. '
                    f'Versuch laenger laufen lassen.',
                    style={'color': 'red'}
                )

            elif deltaTe <= 0.5:

                result_div = html.Div(
                    'Temperaturanstieg der Probe zu gering.',
                    style={'color': 'orange'}
                )

            elif Q_probe <= 0:

                result_div = html.Div(
                    'Energiebilanz negativ – Versuch zu kurz oder starke Verluste.',
                    style={'color': 'red'}
                )

            else:

                m_cube = MATERIALS[material]['masse_g']

                c_e = Q_probe / (m_cube * deltaTe)

                # Literaturwerte
                literature = {
                    'Aluminium': 0.897,
                    'Kupfer': 0.385,
                    'Stahl': 0.470
                }

                c_lit = literature.get(material, 1.0)

                abweichung = abs(c_e - c_lit) / c_lit * 100

                # Qualitätsbewertung
                if abweichung < 15:
                    bg = '#d4edda'
                    border = '#c3e6cb'
                    qual = 'SEHR GUT'
                elif abweichung < 35:
                    bg = '#fff3cd'
                    border = '#ffeaa7'
                    qual = 'BRAUCHBAR'
                else:
                    bg = '#f8d7da'
                    border = '#f5c6cb'
                    qual = 'GROßE ABWEICHUNG'

                result_div = html.Div(
                    [
                        html.Div(
                            f'c = {c_e:.3f} J/(g·K)',
                            style={
                                'fontSize': '30px',
                                'fontWeight': 'bold',
                                'marginBottom': '10px'
                            }
                        ),

                        html.Div(
                            f'Literatur: {c_lit:.3f} J/(g·K)',
                            style={'fontSize': '18px'}
                        ),

                        html.Div(
                            f'Abweichung: {abweichung:.1f} %',
                            style={'fontSize': '18px'}
                        ),

                        html.Div(
                            f'Wärmeverlust korrigiert: {e_loss:.0f} J',
                            style={'fontSize': '16px', 'marginTop': '8px'}
                        ),

                        html.Div(
                            f'Bewertung: {qual}',
                            style={
                                'fontSize': '18px',
                                'fontWeight': 'bold',
                                'marginTop': '10px'
                            }
                        )
                    ],
                    style={
                        'marginTop': '20px',
                        'padding': '20px',
                        'backgroundColor': bg,
                        'border': f'2px solid {border}',
                        'borderRadius': '8px',
                        'textAlign': 'center'
                    }
                )

        except Exception as e:

            result_div = html.Div(
                f'Berechnungsfehler: {str(e)}',
                style={'color': 'red'}
            )
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

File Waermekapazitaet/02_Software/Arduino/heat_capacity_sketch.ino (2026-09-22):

#include <Wire.h>
#include <LiquidCrystal_I2C.h>
#include <OneWire.h>
#include <DallasTemperature.h>
#include <max6675.h>
#include <math.h>   // fuer isnan()

// --- KONFIGURATION ---
// I2C-Adresse 0x27
LiquidCrystal_I2C lcd(0x27, 16, 2);

// Pins fuer MAX6675 (Probestueck/Sample)
const int thermoDO = 12;
const int thermoCS = 10;
const int thermoCLK = 13;
MAX6675 thermocouple(thermoCLK, thermoCS, thermoDO);

// Pin fuer DS18B20 (Wasser)
#define ONE_WIRE_BUS 2
OneWire oneWire(ONE_WIRE_BUS);
DallasTemperature sensors(&oneWire);

// Timing fuer 500ms Update-Rate
unsigned long previousMillis = 0;
const long interval = 500;

void setup() {
  Serial.begin(9600);

  lcd.init();
  lcd.backlight();
  lcd.setCursor(0, 0);
  lcd.print("System Start...");

  sensors.begin();

  delay(1000);
  lcd.clear();
}

void loop() {
  unsigned long currentMillis = millis();

  if (currentMillis - previousMillis >= interval) {
    previousMillis = currentMillis;

    // 1. Sensoren auslesen
    sensors.requestTemperatures();
    float tempWater = sensors.getTempCByIndex(0);   // DS18B20
    float tempSample = thermocouple.readCelsius();  // MAX6675

    // NEU: Fehlerfall pro Sensor VOR dem Senden erkennen.
    // DS18B20 meldet Trennung als -127.0 (DEVICE_DISCONNECTED_C) -- eine
    // normale Zahl, kein Problem fuer JSON.
    // MAX6675 meldet einen offenen Thermoelement-Eingang als NaN --
    // Serial.print(NaN) schreibt oft woertlich "nan" ins JSON, was die
    // GANZE Zeile fuer den JSON-Parser ungueltig macht (auch den jeweils
    // anderen, eigentlich intakten Sensor). Deshalb hier abfangen und
    // stattdessen sauberes JSON-"null" senden.
    bool waterOk = (tempWater != DEVICE_DISCONNECTED_C);
    bool sampleOk = !isnan(tempSample);

    // 2. Daten fuer Python via serieller Schnittstelle (JSON)
    Serial.print("{\"t_water\": ");
    if (waterOk) {
      Serial.print(tempWater);
    } else {
      Serial.print("null");
    }
    Serial.print(", \"t_sample\": ");
    if (sampleOk) {
      Serial.print(tempSample);
    } else {
      Serial.print("null");
    }
    Serial.println("}");

    // 3. LCD Display Update
    updateLCD(tempWater, tempSample, waterOk, sampleOk);
  }
}

void updateLCD(float tW, float tS, bool waterOk, bool sampleOk) {
  // Zeile 1: Wasser (DS18B20)
  lcd.setCursor(0, 0);
  lcd.print("Water: ");
  if (waterOk) {
    lcd.print(tW, 1);
    lcd.print(" C  ");
  } else {
    lcd.print("---  C  ");
  }

  // Zeile 2: Probestueck (MAX6675)
  lcd.setCursor(0, 1);
  lcd.print("Sample: ");
  if (sampleOk) {
    lcd.print(tS, 1);
    lcd.print(" C  ");
  } else {
    lcd.print("---  C  ");
  }
}
